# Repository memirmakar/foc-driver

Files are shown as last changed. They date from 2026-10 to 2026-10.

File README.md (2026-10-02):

# FOC Motor Driver — Rev B

Closed-loop FOC driver for 2-phase steppers, BLDC/PMSM and brushed DC motors.
4 half-bridges (2× DRV8300 + CSD19534Q5A), 36–48 V, 5 A continuous, STM32G431RBT6, CAN-FD.

Driver split: U3 drives HB1+HB2+HB3, U4 drives HB4. A BLDC-only board can be built with a single
DRV8300 (U4, Q7, Q8 and the HB4 parts are DNP; they carry a `Variant` field in the schematic).

| Path | Contents |
|---|---|
| `HANDOVER.md` | Rev B handover: decisions, layout guidance, firmware impacts |
| `FOC-surucu-analiz.md` | Technical audit and price survey |
| `BOM_revB.csv` | Rev B bill of materials |
| `hardware/` | KiCad 10 project (4 sheets: MCU, Interfaces, Power Supply, Power Stage) |
| `hardware/build/` | Schematic PDF, sheet PNGs, ERC report |
| `tools/` | Python generator for the schematics (`build.py`), netlist checks (`check_net.py`), renderer |
| `datasheets/` | Reference datasheets |

The schematics are generated: run `python3 tools/build.py`, then verify with
`kicad-cli sch export netlist` + `python3 tools/check_net.py <netlist>`.
Edits made directly in KiCad are overwritten by the next build.

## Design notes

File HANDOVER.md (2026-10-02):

# FOC Motor Sürücü — Devir (Handover) Dokümanı · Rev B

**Repo:** https://github.com/altinay10/foc-motor-driver (commit `4a430fc`)
**Tarih:** 2026-10-02
**Bu dokümanın amacı:** PCB tasarımını ve komponent değişikliği işini devralacak kişinin, önceki
analiz ve kararları baştan çıkarmak zorunda kalmadan işe başlayabilmesi.

Ekler (bu klasörde):
- `BOM_revB.csv` — revize malzeme listesi (fiyat kaynağı, durum, alternatif sütunlarıyla)
- `FOC-surucu-analiz.md` — ayrıntılı teknik denetim ve fiyat taraması

---

## 1. Proje özeti

Kapalı çevrim FOC motor sürücü kartı.

| Özellik | Hedef |
|---|---|
| Motor tipleri | 2 faz bipolar step (ana hedef), 3 faz BLDC/PMSM, fırçalı DC |
| Güç katı | 4 yarım köprü (HB1–HB4) = 2 H-köprü |
| Bara | 36–48 V |
| Akım | 5 A sürekli/faz, 15 A tepe dayanım |
| Akım ölçümü | In-line shunt + INA240A2, HB1 ve HB3 çıkışında |
| Açı | Kart üstü AS5047D (14 bit, SPI), harici SPI encoder, **yeni:** ABI/Hall girişi |
| Haberleşme | CAN-FD (FDCAN + TJA1051T/3), papatya dizimi |
| PWM | 30 kHz merkez hizalı (20–50 kHz parametre) |
| PCB | 4 katman, hedef 45×45 mm (sığmazsa 50×50) |

Motor eşleşmesi:

| Mod | Bağlantı | Akım ölçümü |
|---|---|---|
| Step | A sargısı HB1–HB2, B sargısı HB3–HB4 | A: RS1, B: RS2 |
| BLDC | U=HB1, V=HB2, W=HB3 (HB4 boşta) — **üç faz da U3'te, tek DRV8300 ile çalışır** | U ve W (V = −U−W) |
| DC | 1–2 adet çift yönlü: HB1+HB2, HB3+HB4 | Her motor için bir shunt |

---

## 2. Repo'nun mevcut durumu (devralırken bilinmesi gerekenler)

| Öğe | Durum |
|---|---|
| `docs/DESIGN.md`, `docs/site/foc-anatomi.html` | Kapsamlı ve büyük ölçüde doğru. **Rev A'yı anlatıyor**, bu dokümandaki Rev B değişiklikleri işlenmedi |
| `hardware/*.kicad_sch` | **~%10–15 tamam.** Sadece MCU, 1× MIC4605, 2× FET, AS5047D, kristal, birkaç C var |
| `hardware/*.kicad_pcb` | **Boş** |
| `hardware/BOM.csv` | Rev A. Yerine `BOM_revB.csv` kullanılacak |
| `firmware/` | Yok (başlanmadı) |
| `simulation/current_loop.py` | Çalışıyor ama **gerilim sınırı modeli hatalı** (bkz. §7) |

Şematikteki tutarsızlıklar:
- MCU sembolü `STM32G474RBTx`. Rev A dokümanı `G431CBT6` diyordu. **Rev B kararı: STM32G431RBT6** (LQFP-64; pin uyumlu sembol `STM32G431RBTx`).
- Net etiketi olarak `PSMQC094N10NS2` kullanılmış (parça numarasına benziyor). Doğru net adlarıyla değiştirilmeli.
- LM5163 (veya LMR38010) için KiCad sembolü yok, çizilmeli. DRV8300 sembolü KiCad standart kütüphanesinde yoksa o da çizilmeli.

---

## 3. Kararlar

### 3.1 Kesinleşenler
| # | Karar | Gerekçe |
|---|---|---|
| K1 | 4 yarım köprü topolojisi | Step 2 faz; aynı donanımla BLDC ve DC |
| K2 | MCU ailesi STM32G4 kalıyor, F4'e geçilmiyor | F4'te CAN-FD, dahili komparatör→BKIN ve CORDIC yok; üstelik daha pahalı ve stoksuz |
| K3 | **Fren chopper kaldırıldı** (Q9, UCC27517, J5 çıktı) | Proje kararı. Etkisi için bkz. §6 R5 |
| K4 | In-line akım ölçümü ve INA240A2 korunuyor | Kalite. Low-side + dahili OPAMP daha ucuz ama yüksek modülasyonda ölçüm penceresi daralıyor |
| K5 | Bootstrap gate sürüşü (charge pump yok) | Tutma torku PWM ile üretiliyor (duruşta duty ≈ %42/%58), %100 duty gerekmiyor |
| K6 | Kapasitör azaltarak maliyet düşürülmeyecek | EMI ve aşırı gerilim |
| K7 | **Sürücü dağılımı: U3 = HB1+HB2+HB3, U4 = HB4** (2026-10-03) | BLDC kartı tek DRV8300 ile üretilebilsin (U4, Q7, Q8 ve HB4 parçaları DNP). Bedeli: step modunda B sargısının iki bacağı farklı entegrede (§4.2) |

### 3.2 Önerilen, onay bekleyen
| # | Öneri | Not |
|---|---|---|
| O1 | **4× MIC4605 → 2× DRV8300DPWR** | Rev A'daki MIC4605-**1** zaten yanlış varyanttı (çift giriş). DRV8300: sabit 150–280 ns dead-time + çapraz iletim kilidi, dahili bootstrap diyotu, ~2.6 $ ucuz |
| O2 | Alternatif: 2× **DRV8353/DRV8350** | FET başına VDS aşırı akım izleme ve fault pini. Daha pahalı; TR kanallarında stok yok. Fiyat araştırılmadı |
| O3 | **STM32G431RBT6** (LQFP-64) | 8 PWM + ABI/Hall + BKIN2 için pin gerekli. Farnell'de CBT6'dan ucuz |
| O4 | 12 V buck → **LM5163** (100 V) | LMR38010'un 80 V mutlak maksimumu TVS kıstırma gerilimi altında kalıyor. DigiKey stoku 0, tedarik kontrol edilmeli |

### 3.3 Açık (karar verilmeli)
- Ters polarite P-FET parça numarası (≥100 V, gate zener'li)
- Bulk kapasitör parça numarası (100 V, ripple akımı hesabına göre)
- Konnektör ailesi (J1/J2 akımı: zincirdeki **toplam** kart akımını taşıyacak)
- GVDD yük anahtarı parçası (§4.4)
- Termal çözüm: soğutucu / motor flanşına termal pad / fan (§4.6)

---

## 4. PCB tasarımcısı için

### 4.1 Rev B blok yapısı
```
48V ─ J1/J2 ─ Q10 ters polarite (P-FET + zener) ─ D1 TVS ─ C_BULK (100V) ─┬─ HB1..HB4 (Q1-Q8)
                                                                           │     └─ alt FET source'lari ─ RS3 (bara shunt) ─ GND
                                                                           └─ U7 LM5163 ─ 12V ─┬─ U10 yuk anahtari ─ GVDD ─ U3 (HB1-3) / U4 (HB4) DRV8300
                                                                                               └─ U8 LMR51430 ─ 3.3V ─ MCU, INA240, CAN, AS5047D
                                                                                                                  └─ FB1 ─ 3.3VA (ADC ref, INA240 REF1, encoder)
```

### 4.2 Gate driver yerleşimi (DRV8300)
- **U3 = HB1 + HB2 + HB3, U4 = HB4 (K7).** BLDC'de U/V/W üç fazı aynı entegrede (kanallar arası gecikme eşleşmesi ±30 ns); BLDC varyantında U4 ve HB4 takılmaz.
- **Bedeli:** step modunda B sargısı (HB3–HB4) iki entegreye bölünür; entegreler arası gecikme farkı 110 ns'ye kadar çıkabilir. 48 V / 30 kHz'te bu ~0.16 V ortalama gerilim hatası demek, büyük ölçüde sabit ofset; kapalı çevrim akım döngüsü (PI integratörü) telafi eder. Firmware'de dead-time kompanzasyonuna bacak başına ofset kalibrasyonu eklenmeli.
- **U3 ve HB1–HB3 FET'leri** birlikte yerleşmeli; U4 HB4'ün yanında durur.
- **Fren chopper (opsiyonel, DNP):** U4 kanal B alt çıkışı (GLB) → Q9 + J9; kontrol BRK_PWM (PB6, TIM8_CH1). U4 kanal C kullanılmıyor. BLDC varyantında (U4 yok) chopper da yoktur.
- **BLDC varyantı DNP listesi:** U4, Q7, Q8, U4 GVDD kondansatörleri, HB4 gate ağı, HB4 bootstrap ve C_HB kondansatörleri. Şematikte bu parçalarda `Variant` alanı dolu. Firmware, U4 takılı değilken step modunu engellemeli.
- GH/SH ve GL/GND döngüleri kısa olmalı. Bootstrap kondansatörü BSTx–SHx pinlerinin dibine konmalı. GVDD'ye ≥10 µF.
- DRV8300'ün tek GND pini var (alt gate dönüşü de buradan). GND'yi alt FET source bölgesine kısa yoldan bağlayın; RS3 bara shunt'ının hangi tarafına referanslanacağını yerleşimde netleştirin (öneri: driver GND = RS3'ün GND tarafı, alt FET source'ları RS3'ün üst tarafı; gate dönüş yolu shunt üzerinden geçer ama düşüm mV mertebesinde).
- Gate direnci: turn-on 33 Ω, turn-off 10 Ω + diyot. **FET'in kapanma süresi 150 ns'nin (min dead-time) altında kalmalı.** Turn-off direnci büyütülmemeli.
- Girişlerde (INHx/INLx) dahili pull-down var. Yine de MCU reset durumunda köprünün kapalı kaldığını doğrulamak için hatlara harici 10–100 kΩ pull-down konabilir.

### 4.3 Akım ölçümü ve koruma
- RS1/RS2: **Kelvin** bağlantı, INA240 girişlerine kısa, sıkı ve GND korumalı diferansiyel çift.
- INA240 **REF1 → 3.3VA** (dijital 3V3'e değil). REF2 → AGND.
- **RS3 (yeni):** tüm alt FET source'ları → RS3 → GND. G431 dahili OPAMP (PGA) → dahili COMP → TIM1_BKIN. Böylece HB2/HB4 kısa devresi, FET delinmesi ve shoot-through yakalanır (in-line shunt'lar bunları görmez).
- Faz akımı sinyalleri **COMP_INP olabilen pinlere** atanmalı (§5).

### 4.4 Donanımsal ENABLE (önemli, Rev A'dan farklı)
DRV8300'de EN pini **yok**. Bu yüzden ENABLE şöyle uygulanmalı:
1. Harici ENABLE (J6) → **TIM1_BKIN2** pini: CPU'dan bağımsız olarak timer çıkışlarını idle'a (tüm FET'ler kapalı) çeker.
2. Harici ENABLE **AND** MCU_EN (U11, 74LVC1G08) → **U10 GVDD yük anahtarı**: 12 V gate besleme kesilir, DRV8300 UVLO'ya girer, tüm FET'ler kapanır. MCU kilitlense bile çalışır.
3. ENABLE hattına pull-down: konnektör çıkarılırsa sürücü kapalı kalmalı.

### 4.5 Güç katı ve EMI
- Her bacakta **2× 2.2 µF 100 V X7R 1210** (C_HB), üst FET drain ile alt FET source arasında, mümkün olan en küçük döngüde.
- Güç döngüsü: bulk → üst FET → alt FET → RS3 → GND, en küçük alan. 4 bacak birbirinin kopyası olarak yerleşmeli.
- Katman dizilimi (Rev A'dan): Sinyal/Güç — **kesintisiz GND** — GND/Güç — Sinyal. GND düzlemi bölünmeyecek.
- Encoder ve analog bölge anahtarlamadan fiziksel olarak ayrı; besleme FB1 üzerinden.
- **AS5047D alt yüzde, kartın tam merkezinde** (mıknatısla hizalı). Yerleşim buradan başlar.

### 4.6 Termal
- Tahmini kayıp 3.3 W (30 kHz) – 4.7 W (50 kHz). 45×45 mm'de doğal konveksiyonla **+55…80 °C** artış bekleniyor → soğutma şart.
- FET altlarında termal via tarlası, iç katman bakırları geniş tutulmalı.
- NTC (RT1) FET bakırına yakın.
- Montaj delikleri / termal pad alanı soğutucu veya motor flanşı için planlanmalı.

### 4.7 CAN ve konnektörler
- J1/J2: 48 V + GND + CANH + CANL. Akım değeri zincirdeki toplam akıma göre seçilmeli.
- CAN: **split terminasyon** (2× 60.4 Ω + 4.7 nF, jumper ile seçilebilir) + **PESD2CANFD** ESD.
- J5 (fren direnci) kaldırıldı.
- **J8 (yeni):** ABI encoder / Hall, 5 pin: 5V, GND, CH1, CH2, CH3. Her hatta seri direnç + 3.3 V'a klemp, seçilebilir pull-up (open-collector Hall için).
- Q10 P-FET: gate-source 12–15 V zener + seri direnç (48 V, V_GS ±20 V sınırını aşar).
- Sıcak takma (hot-plug) ani akımı için soft-start/inrush sınırlama değerlendirilmeli.

---

## 5. MCU sinyal listesi (STM32G431RBT6) — pin haritası CubeMX'te yapılacak

Rev A'daki LQFP-48 haritası **geçersiz.** Aşağıdaki sinyaller ve kısıtlarla CubeMX'te yeni harita çıkarılmalı.

| Sinyal | Adet | Çevrebirim | Kısıt |
|---|---|---|---|
| PWM INH/INL HB1–HB3 | 6 | TIM1 CH1/CH1N, CH2/CH2N, CH3/CH3N | Complementary + DTG |
| PWM INH/INL HB4 | 2 | TIM1 CH4/CH4N **veya** TIM1'e senkron TIM8 | CH4N pin müsaitliğini doğrula |
| Faz A akımı | 1 | ADC + **COMP_INP** | COMP3_INP = PA0/PC1, COMP1_INP = PA1/PB1, COMP2_INP = PA7/PA3, COMP4_INP = PB0 |
| Faz B akımı | 1 | ADC + **COMP_INP** | Rev A'daki PA4 COMP girişi değildi, **kullanılmamalı** |
| Bara akımı (RS3) | 1 | OPAMP VINP → dahili COMP → TIM1_BKIN | OPAMP giriş pinini doğrula |
| Harici ENABLE | 1 | TIM1_BKIN2 + GPIO | + U11 AND kapısına |
| MCU_EN | 1 | GPIO out | U11'e |
| FDCAN1 RX/TX | 2 | FDCAN1 | PB8 kullanılırsa `nSWBOOT0 = 0` option byte |
| SPI1 (AS5047D) | 4 | SPI1 | |
| SPI2 (harici encoder) | 4 | SPI2 | |
| ABI/Hall (J8) | 3 | TIM3 veya TIM4 CH1–CH3 | Encoder modu + Hall (XOR) arayüzü aynı timer'da |
| VBUS, NTC, CAN adres | 3 | ADC | |
| USART2 debug | 2 | USART2 | |
| GPIO giriş ×2, aux çıkış ×1 | 3 | GPIO | Aux = Q11 |
| LED ×2 | 2 | GPIO | |
| SWD, OSC_IN/OUT, NRST | 5 | | |

---

## 6. Bilinen sorunlar ve riskler

| # | Sorun | Önem | Durum |
|---|---|---|---|
| R1 | MIC4605-1 yanlış varyant (çift giriş); tek PWM planıyla köprü çalışmazdı | Kritik | DRV8300 ile çözülüyor (O1) |
| R2 | Faz B'de donanım aşırı akım koruması yok (PA4 COMP girişi değil), A'da tek yönlü | Kritik | Pin haritası + RS3 ile çözülecek |
| R3 | HB2/HB4 kısa devresi ve shoot-through hiçbir sensörde görünmüyor | Kritik | RS3 bara shunt'ı (yeni) |
| R4 | ENABLE yazılıma bağlıydı | Kritik | §4.4 |
| R5 | **Chopper kaldırıldı** → rejenerasyonda bara gerilimi yükselir, TVS sürekli enerjiyi kaldıramaz | Yüksek | Firmware: VBUS izleme, yavaşlama rampası sınırı, gerekirse sıfır vektör frenleme. Opsiyonel chopper footprint (§4.2) |
| R6 | Gerilim koordinasyonu: 63 V kapasitör, SMBJ58A kıstırma 93.6 V > LMR38010 80 V | Yüksek | 100 V kapasitör, SMCJ54A, LM5163 |
| R7 | Termal: soğutmasız +55…80 °C | Yüksek | §4.6 |
| R8 | DRV8300 sabit 150–280 ns dead-time → bacak başına ~0.3 V bozulma | Orta | Firmware'de dead-time kompanzasyonu (kalibrasyonlu) |
| R9 | DRV8300'de fault pini, VDS izleme, sıcaklık koruması yok | Orta | RS3 + NTC + firmware; ya da O2 (DRV8353) |
| R10 | Simülasyon gerilim sınırı hatalı → hız tavanı ~%30 iyimser (571 → ~405 rpm) | Orta | §7 |
| R11 | CAN terminasyonu ve ESD yoktu | Orta | BOM'a eklendi |
| R12 | Bootstrap %100 duty'de dolamaz | Düşük | Firmware duty sınırı %97–98 |

---

## 7. Firmware'e etki eden donanım kararları

- **Duty sınırı:** SVPWM dahil %97–98 (bootstrap yenilenmesi için ≥0.5–1 µs off süresi).
- **Bootstrap ön şarj:** Her enable'da ve Hi-Z sonrasında alt FET'ler kısa süre açılmalı.
- **Dead-time:** MCU DTG yedek amaçlı (ör. 50–100 ns). Etkin dead-time ~215 ns (driver). Akım yönüne göre gerilim kompanzasyonu gerekir.
- **nSWBOOT0 = 0** option byte (FDCAN RX PB8'e düşerse) — ilk programlamada.
- **Chopper yok:** VBUS eşik izleme, rejeneratif frenlemede akım/rampa sınırı.
- **Simülasyon düzeltmesi:** `current_loop.py` içindeki `max_current_at_speed` dq'da kare değil daire sınırı kullanmalı: `(R·iq + ωe·λm)² + (ωe·L·iq)² ≤ Vbus²`. λm tutma torkundan türetilirken `|i| = √2·I_anma` alınmalı (tutma torku iki faz birden enerjiliyken ölçülür).

---

## 8. Komponent değişikliği iş paketi

Ayrıntı `BOM_revB.csv` içinde. Fiyatlar 2026-10-02 taramasından, 10 adet kademesi.

**Sonuç:** komponent toplamı Rev A **~61.5 $ → Rev B ~48.5 $** (PCB hariç). Bu toplamın ~22 $'ı "TAHMIN" veya "BOM tahmini" kaynaklı; doğrulanması gerekiyor.

Tedarik notları:
- **Özdisan:** Çoğu parça stoksuz, "Fiyat ve Stok Talep Et". Stoklu ve en ucuz olduğu kalem CSD19534Q5A (0.46 $, 474 adet). DRV8300DPWR 0.47 $ (talep üzerine).
- **DigiKey:** MCU, INA240, DRV8300, TJA1051 stoklu. CSD19534Q5A sadece 3 adet, LM5163 stok 0.
- **Farnell TR:** G431RBT6 en ucuz burada (10+: 4.79 €). DRV8300 ve LMR38010 yok. INA240A2 sadece TSSOP (A2PWR).
- AS5047D artık Infineon markasıyla satılıyor: DigiKey `AS5047D-ATST-TSSOP14`. Farnell'deki ams AS5047D-ATSM "üretimden kaldırıldı".

Yapılacaklar:
- [ ] "TAHMIN" ve "ACIK" satırlarının parça numarası ve fiyatını netleştir (Q10, Q11, C_BULK, U10, D1, D12, konnektörler)
- [ ] LMR51430'u doğrula; 150 mA yük için daha küçük/ucuz bir buck değerlendir
- [ ] LM5163 stoğu yoksa LM5164 veya başka bir 100 V buck seç (LMR38010 ancak TVS stratejisi değişirse)
- [ ] O1/O2 kararı: DRV8300 mü DRV8353 mü (DRV8353 fiyat/stok araştırması)
- [ ] Bulk kapasitör ripple akımı hesabı (2 H-köprü, 5 A, 30 kHz)
- [ ] Her parça için KiCad sembol + footprint (proje kütüphanesine, `${KIPRJMOD}` ile)
- [ ] BLDC (tek sürücü) varyantı için ayrı BOM / montaj varyantı (K7)

---

## 9. Bring-up ve doğrulama listesi

1. Saat, SWD, LED, UART; `nSWBOOT0 = 0`; CAN bağlıyken normal boot.
2. GVDD yük anahtarı ve ENABLE zinciri: ENABLE düşünce GVDD'nin kesildiğini ölç.
3. Motorsuz, düşük bara geriliminde (12–24 V) PWM: her bacakta **V_GS(üst) ve V_GS(alt) aynı anda** osiloskopla → dead-time ve turn-off < 150 ns doğrulaması. Sonra 48 V'ta ve sıcakken tekrar.
4. RS3 + COMP → BKIN: kontrollü kısa devre testi (akım sınırlı kaynakla).
5. INA240 ofset kalibrasyonu (PWM açık, motor bağlı değil).
6. AS5047D ham açı → açık çevrim döndürme → encoder↔elektriksel açı kalibrasyon tablosu.
7. Akım döngüsü (tork modu), dead-time kompanzasyonu ayarı.
8. Hız ve pozisyon döngüsü; tutma torku testi (5 A, duruşta, termal gözlem).
9. Rejeneratif frenleme testi: chopper yokken VBUS yükselmesini ölç.
10. İki kartla CAN-FD papatya dizimi.

---

## 10. Kaynaklar
- DRV8300 datasheet (TI SLVSFG5D): https://www.ti.com/lit/ds/symlink/drv8300.pdf
- MIC4605 datasheet (Microchip DS20005853): https://download.mikroe.com/documents/datasheets/mic4605.pdf
- STM32G431 datasheet: https://www.mouser.com/datasheet/2/389/stm32g431c6-1600866.pdf
- Fiyat/stok: digikey.com, tr.farnell.com, ozdisan.com (2026-10-02)

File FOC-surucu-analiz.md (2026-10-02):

# FOC Motor Sürücü (altinay10/foc-motor-driver) — Teknik Denetim ve Maliyet Analizi

Tarih: 2026-10-02 · İncelenen commit: `4a430fc` (Initial import)

---

## 0. Kontrol listesi (neye bakıldı)

| # | Konu | Sonuç |
|---|---|---|
| 1 | Repo durumu (şematik / PCB / firmware olgunluğu) | ⚠️ Erken aşama |
| 2 | Gate driver seçimi ve pin planı tutarlılığı | ❌ **Kritik hata** |
| 3 | Dead-time / shoot-through koruması | ⚠️ Kısmen |
| 4 | Aşırı akım / kısa devre koruması | ❌ Boşluk var |
| 5 | ENABLE / güvenli durma | ❌ Yazılıma bağlı |
| 6 | Gerilim koordinasyonu (TVS, kapasitör, regülatör, driver) | ❌ Tutarsız |
| 7 | Ters polarite / hot-plug / daisy-chain gücü | ⚠️ Eksik detay |
| 8 | Akım ölçüm zinciri (INA240, referans, ADC) | ✅ İyi, küçük düzeltme |
| 9 | MCU seçimi, pin bütçesi, çevrebirim eşleşmesi | ⚠️ Pin yetmiyor |
| 10 | Simülasyon / hız-tork zarfı hesabı | ❌ Hesap hatası |
| 11 | Termal bütçe | ⚠️ Soğutmasız tutmaz |
| 12 | CAN-FD arayüzü | ⚠️ Terminasyon/ESD yok |
| 13 | 4 yarım köprü / step motor desteği | ✅ |
| 14 | BLDC desteği | ✅ FOC için, sınırlamalarla |
| 15 | DC motor desteği (donanım değişmeden) | ✅ Sınırlamalarla |
| 16 | G4 → F4 değişimi | ❌ Önerilmez |
| 17 | 4× MIC4605 → 2× DRV8300 | ✅ Uygulanabilir, önerilir |
| 18 | Fiyat/stok (DigiKey, Farnell, Özdisan) | Aşağıda |

---

## 1. Genel değerlendirme

**Tasarım düşüncesi güçlü, donanım uygulaması henüz yok denecek kadar az.**

- `docs/DESIGN.md` ve `foc-anatomi.html` iyi yazılmış; topoloji (4 yarım köprü), in-line shunt + INA240,
  50 kutup çifti etkisi, encoder kalibrasyon zorunluluğu, anti-windup, dq ileri besleme gibi kararlar doğru.
- **Ama:**
  - Şematikte sadece ~30 sembol var: 1× MIC4605, 2× FET, MCU, AS5047D, kristal, birkaç kapasitör.
    Güç katı, akım ölçümü, CAN, regülatörler, konnektörler **çizilmemiş**.
  - Şematikteki MCU sembolü **STM32G474RBTx (LQFP-64)**, dokümandaki ise **STM32G431CBT6 (LQFP-48)** — tutarsız.
  - Net etiketi olarak `PSMQC094N10NS2` kullanılmış (parça numarasına benziyor, net adı değil).
  - PCB dosyası boş (80 bayt), firmware klasörü yok.
  - BOM'daki fiyatlar EKOM'dan ve birçok satır "ACIK" (parça seçilmemiş).

Sonuç olarak "ne kadar iyi" sorusunun cevabı: **konsept seviyesinde 7/10, uygulanabilir donanım seviyesinde
henüz değerlendirilemez.** Aşağıdaki kritik hatalar düzeltilmeden kart basılırsa çalışmaz ya da güvenli olmaz.

---

## 2. Kritik bulgular (kart basılmadan önce düzeltilmeli)

### 2.1 ❌ MIC4605-1 yanlış varyant — tasarım bu haliyle çalışmaz
BOM: `MIC4605-1YM … tek PWM girişi`. Datasheet (DS20005853):
- **MIC4605-1 = çift giriş (HI + LI)**
- **MIC4605-2 = tek PWM girişi**

Tasarımın pin planı tek PWM + ortak EN (4 PWM + 1 EN). -1 ile LI pini 300 kΩ dahili pull-down ile
sürekli düşük kalır → alt FET hiç açılmaz → bootstrap kondansatörü dolmaz → üst FET de sürülemez.
**Çözüm:** ya MIC4605-**2** (aynı fiyat, aynı kılıf), ya da aşağıdaki DRV8300 + LQFP-64 seçeneği.

### 2.2 ❌ Aşırı akım koruması pin eşleşmesi tutmuyor
Doküman: "COMP → TIM1_BKIN, harici parça yok". STM32G431'de komparatör pozitif girişleri:
COMP1_INP = PA1/PB1, COMP2_INP = PA7/PA3, COMP3_INP = PA0/PC1, COMP4_INP = PB0/PE7.
- Faz A akımı **PA0** → COMP3 ✓ (ama yalnız **tek yön**; stepte akım çift yönlü)
- Faz B akımı **PA4** → **hiçbir komparatörün INP'si değil** ✗ → B fazında donanım OCP yok.
- Her pin yalnız bir komparatöre gidiyor → çift yönlü (±) eşik için ya sinyali iki pine bağlamak ya da
  ayrı bir bara akımı ölçümü gerekir. (Pin eşleşmesini CubeMX'te teyit edin.)

### 2.3 ❌ HB2 / HB4 ve shoot-through için hiç koruma yok
Shunt'lar yalnız HB1 ve HB3 çıkışında. Şu arızaları **hiçbir sensör görmez**:
- A− veya B− terminalinin GND'ye / VBUS'a kısa devresi (akım HB2/HB4 FET'inden geçer, shunt'tan geçmez)
- Köprü içi shoot-through ya da delinmiş FET (in-line shunt köprü içi akımı görmez)

**Çözüm (ucuz):** DC bara dönüşüne tek bir low-side shunt (2–5 mΩ) + G431'in dahili OPAMP'ı (PGA) +
dahili COMP → TIM1_BKIN. ~0.5 $ ek maliyet, tüm köprü arızalarını ve bara akımını kapsar.
Bonus: bara akımı ölçümü güç/rejenerasyon kestirimi ve fren chopper kontrolü için de işe yarar.

### 2.4 ❌ "Donanımsal ENABLE" aslında yazılımsal
Harici ENABLE girişi PB7'ye (GPIO in) gidiyor; driver EN'i PB6'dan MCU sürüyor. MCU kilitlenirse veya
firmware hatası varsa ENABLE düşse bile köprü kapanmaz. DESIGN.md §11'deki "Sertifikalı STO yerine
donanımsal ENABLE yeterli" iddiası bu şemayla geçersiz.
**Çözüm:** ENABLE'ı (a) bir 74LVC1G08 AND kapısıyla driver EN hattına donanımsal olarak bağlayın,
(b) ayrıca TIM1_BKIN2 pinine verin. EN ve PWM hatlarına pull-down koyun (reset/boot sırasında MCU pinleri
yüzerken köprü kapalı kalsın).

### 2.5 ❌ Gerilim koordinasyonu tutarsız
| Eleman | Değer |
|---|---|
| Bara | 36–48 V (13S Li-ion dolu: **54.6 V**) |
| Fren chopper devreye girme | ~54 V ← 13S dolu batarya ile çakışır |
| SMBJ58A | V_BR min **64.4 V**, kıstırma V_C **93.6 V** (@I_pp) |
| Bulk kapasitör | **63 V** ← TVS iletime geçmeden aşılır |
| LMR38010 | abs max **80 V** ← TVS kıstırması bunu aşar |
| MIC4605 HS | abs max 90 V |

**Çözüm:** Kapasitörleri 80–100 V'a çıkarın; 12 V buck'ı 100 V'luk LM5163/LM5164'e geçirin (fiyat aynı);
TVS'i SMCJ54A gibi daha yüksek I_pp'li bir parçayla değiştirin ki kıstırma gerilimi düşük kalsın;
asıl aşırı gerilim koruması fren chopper'dır, eşiğini parametre yapın.

### 2.6 ❌ Simülasyondaki gerilim sınırı hatalı → hız tavanı ~%30 iyimser
`simulation/current_loop.py` gerilim sınırını **dq çerçevesinde kare** alıyor (|v_d| ≤ Vbus ve |v_q| ≤ Vbus
ayrı ayrı). Bağımsız H-köprülerin kare sınırı **sabit αβ çerçevesindedir**; dq çerçevesi döndükçe bu kare
de döner, her açıda garanti olan sınır içteki dairedir: √(v_d² + v_q²) ≤ Vbus.

Yeniden hesap (NEMA23, R=1.5 Ω, L=3 mH, 48 V, 5 A):

| λm varsayımı | Model | Tam akımın korunduğu son hız |
|---|---|---|
| 13.6 mWb (repo) | kare (repo) | 9.5 dev/s (571 rpm) |
| 13.6 mWb (repo) | **daire (doğru)** | **6.75 dev/s (405 rpm)** |
| 9.6 mWb | daire | 7.8 dev/s (471 rpm) |

Ek not: λm tutma torkundan `T/(p·I)` ile türetilmiş. Tutma torku iki faz birden anma akımındayken
ölçülür, bu yüzden |i| = √2·I_anma alınmalı; böyle hesaplanınca λm ≈ 9.6 mWb olur. Tablodaki 3.39 N·m
gibi değerler de 2.8 A'lik bir motoru 5 A'de lineer kabul ediyor; doyum nedeniyle gerçekte daha düşük çıkar.

---

## 3. Dead-time koruması — tam mı?

**Kısa cevap: Tam değil.** Tek katmanlı ve doğrulanmamış.

| Katman | Mevcut tasarım (MIC4605-2 varsayımıyla) |
|---|---|
| MCU dead-time (TIM1 DTG) | **Yok.** Tek PWM girişli driver'da complementary çıkış kullanılmıyor |
| Driver dead-time | Adaptif: HS→LS geçişinde switch node (HS < 2.2 V) izleniyor ✓; LS→HS geçişinde ise **LO pin** gerilimi (< 1.9 V) izleniyor |
| Driver interlock | Var (tek PWM girişiyle iki çıkışın birden açık olması mantıksal olarak imkânsız) ✓ |
| Arıza geri bildirimi | Yok (MIC4605'te fault pini yok) |
| Shoot-through algılama | Yok (bkz. 2.3) |

**Zayıf nokta:** LO pini 1.9 V'un altına indiğinde FET kapısı hâlâ yüksek olabilir, çünkü arada
10 Ω + diyot + FET'in iç R_g'si var. Datasheet de harici sönümleme direncinin kapanma gecikmesini
artırdığını açıkça yazıyor. Datasheet'teki dead-time < 20 ns. Pratikte bu yönde marjı sağlayan şey,
üst FET'in 33 Ω üzerinden yavaş açılması — bu da tesadüfi bir marj, tasarlanmış değil.

**Ek riskler:**
- %100 duty'de bootstrap şarj olamaz. `duty = 0.5 + v/(2·Vbus)` doyumda 1'e gider → firmware'de
  %95–97 ile sınırlanmalı.
- Adaptif dead-time akım yönüne ve sıcaklığa göre değiştiği için, düşük hızda gerekli olan
  dead-time kompanzasyonu daha zor (sabit bir dead-time ile deterministik olurdu).

**Önerilen çözüm (çift katman):**
complementary PWM + MCU DTG (ör. 100–150 ns) **+** driver'ın kendi interlock'u.
Bunun için DRV8300D (6x giriş, sabit 200 ns + cross-conduction engeli) veya MIC4605-1 (HI/LI, adaptif +
"ilk açılan kazanır" kilidi) kullanılabilir — ikisi de yarım köprü başına 2 pin ister → LQFP-64 MCU.
Bring-up'ta her köprüde V_GS(alt) ile V_GS(üst) aynı anda osiloskopla ölçülmeli.

---

## 4. 4× MIC4605 yerine 2× DRV8300 olur mu?

Önce bir düzeltme: Mevcut tasarımda her MOSFET için ayrı driver yok, **her yarım köprü için bir driver**
var (8 FET'e 4 driver). DRV8300 tek pakette **3 yarım köprü** sürer → 2 adet = 6 kanal.

**Evet, olur ve önerilir.** Kanal dağılımı:

| Kanal | Kullanım |
|---|---|
| 1–4 | HB1–HB4 |
| 5 (yalnız low-side) | Fren chopper FET'i → **UCC27517 kalkar** |
| 6 | Yedek (ör. ikinci low-side çıkış) |

| | 4× MIC4605-2 | 2× DRV8300DPW |
|---|---|---|
| Gerilim | HS 90 V abs | SHx 85 V çalışma, BST 125 V abs, SHx −22 V tolerans |
| Dead-time | Adaptif (~20 ns) | Sabit 200 ns (TSSOP) + cross-conduction engeli |
| Giriş | 1 PWM / köprü | 2 giriş / köprü (6x) → **MCU dead-time + bacak başına Hi-Z** |
| Bootstrap diyot | Dahili | Dahili (D versiyonu) |
| Gate akımı | 1 A | 0.75 A kaynak / 1.5 A çekme (zaten R_g ile yavaşlatılıyor) |
| Fiyat (10 adet) | 4 × 1.05 $ = **4.20 $** (DK) | 2 × 0.81 $ = **1.62 $** (DK); Özdisan 0.47 $/adet |
| UCC27517 | Gerekli (~0.6–1.2 $) | Gereksiz |

**Bedeli:** 8 PWM hattı gerekiyor. LQFP-48'de pin kalmadığı için **STM32G431RBT6 (LQFP-64)** gerekir —
Farnell'de CBT6'dan daha ucuz (aşağıda). Dördüncü köprü için TIM1_CH4/CH4N veya TIM1 ile senkronize
TIM8 kullanılabilir (CubeMX'te teyit edin).

Varyant notu: `DRV8300DPWR` = INL non-inverting (6x complementary PWM için doğru seçim, en çok stoklu).
`DRV8300DIPWR` = INL inverting (INH=INL bağlanırsa tek-PWM modu, ama DigiKey'de daha pahalı).

---

## 5. 4 faz / step + BLDC + DC motor desteği

### 5.1 Step motor (2 faz bipolar, 4 yarım köprü) — ✅ Tam destek
TIM1 CH1–CH4 bağımsız, iki H-köprü, iki in-line shunt. 6/8 telli unipolar motorlar bipolar olarak bağlanabilir.

### 5.2 BLDC (3 faz) — ✅ FOC için evet, kısıtlarla
- HB1/HB2/HB3 = U/V/W; shunt'lar U ve W'de, V = −(U+W). FOC + SVPWM için yeterli.
- **Kısıtlar:**
  - Ortak EN olduğu için bacak başına Hi-Z yok → 6-step trapez ve BEMF sıfır geçişli sensörsüz çalışma yapılamaz (sensörlü ya da gözlemcili FOC yapılabilir).
  - **Hall girişi yok** (J6'da yalnız 2 giriş var, 3 gerekir, 5 V seviye koruması da yok).
  - Açı ölçümü yalnız kart üstü AS5047D (mıknatıs kartın merkezine hizalı olmalı) veya SPI harici encoder ile.
  - Faz gerilimi ölçümü yok (sensörsüz başlatma / flying start zorlaşır).
- DRV8300 + LQFP-64 önerisi bu kısıtların ilk ikisini kaldırır.

### 5.3 DC motor (donanım değiştirmeden) — ✅ Evet, kısıtlarla
- 1 adet çift yönlü fırçalı DC: HB1+HB2, akım RS1 ile ölçülür ✓ (tork/akım kontrolü, rejeneratif fren).
- 2 adet çift yönlü DC: HB1+HB2 ve HB3+HB4, her birinde bir shunt ✓.
- 4 adet tek yönlü DC (her yarım köprüden GND'ye) yapılabilir, ama yalnız ikisinin akımı ölçülür.
- **Kısıtlar:**
  - **Quadrature (ABI) encoder girişi yok** — çoğu DC redüktörlü motorda ABI encoder var → pozisyon kontrolü için donanım değişikliği gerekir (LQFP-64 ile TIM3/TIM4 encoder modu).
  - Ortak EN yüzünden köprü başına "coast" (serbest bırakma) yok; yalnız fren (iki bacak aynı duty) mümkün.
  - 4 mΩ shunt ile ölçüm aralığı ±8.25 A; yüksek akımlı DC motor için 2 mΩ seçeneği var.

---

## 6. G431 yerine F4? — ❌ Önerilmez

| MCU | CAN | CORDIC/FMAC | Dahili COMP→BKIN | DigiKey 10 ad. | DigiKey 100 ad. | Stok (DK) |
|---|---|---|---|---|---|---|
| **STM32G431CBT6** (mevcut) | **FDCAN (CAN-FD)** | ✓ | ✓ (4×) | 5.39 $ | 4.53 $ | 280 |
| **STM32G431RBT6** (öneri, LQFP-64) | FDCAN | ✓ | ✓ | 5.43 $ | 4.57 $ | 6575 |
| STM32G431C8T6 (64 KB) | FDCAN | ✓ | ✓ | 4.40 $ | 3.68 $ | 18 |
| STM32F446RET6 | bxCAN (FD yok) | ✗ | ✗ | 7.98 $ | 6.78 $ | 0 |
| STM32F405RGT6 | bxCAN (FD yok) | ✗ | ✗ | 9.78 $ | 8.35 $ | 0 |

F4'ler **daha pahalı**, stokta yok ve README'deki CAN-FD papatya dizimi şartını karşılamıyor.
F401/F411 gibi ucuz F4'lerde hiç CAN yok. G4 bu iş için hem en ucuz hem en doğru aile.
**Öneri:** G431**RB**T6 — Farnell'de CBT6'dan ucuz (10+: 4.79 € vs 5.66 €), stok bol ve pin sorununu çözüyor.
(Şematikte zaten LQFP-64 G474 sembolü var; G474 gereksiz pahalı, G431RB yeterli.)

---

## 7. Diğer bulgular (orta / düşük öncelik)

1. **Termal:** 3.3–4.7 W kayıp, 45×45 mm kartta doğal konveksiyonla ~16–25 K/W → **+55…80 °C** artış.
   Motor flanşına termal pad ile ısı yolu, küçük bir soğutucu ya da hava akışı şart. Alternatif olarak dV/dt
   0.5 yerine ~1.2 V/ns hedeflenirse anahtarlama kaybı düşer.
2. **INA240 REF1 → +3.3 V (dijital)**, ADC referansı ise +3.3VA (FB1 ile filtreli). REF1'i 3.3VA'ya
   bağlayın; ratiometrik olsun, dijital gürültü ofset olarak ölçüme binmesin.
3. **Low-side yerine in-line seçiminin gerekçesi yanlış ifade edilmiş:** Tasarımın kendi modülasyonunda
   (duty = 0.5 + v/2Vbus) duruşta duty ≈ %50, yani low-side penceresi en geniş. Low-side ölçümün kör
   kaldığı yer **yüksek modülasyon**, düşük duty değil. In-line yine de daha iyi bir seçim (pencere kısıtı yok),
   INA240'ı koruyun — sadece dokümandaki gerekçe düzeltilmeli.
4. **Yarım köprü başına lokal 100 V MLCC** (ör. 2× 2.2 µF 1210 X7R) BOM'da açıkça yok ("PASIF" içinde
   kaybolmuş). EMI ve aşırı gerilim sıçraması için zorunlu — **maliyet düşürme sırasında kesinlikle çıkarılmamalı.**
5. **Ters polarite P-FET:** 48 V'ta V_GS ±20 V'u aşar → gate–source zener (12–15 V) + seri direnç gerekli.
   Daisy-chain'de hot-plug ani akımı (bulk kapasitör şarjı) konnektörde ark yapar → soft-start veya
   inrush sınırlayıcı (ör. LM74700 + FET ya da NTC) düşünün. Papatya dizimindeki ilk konnektörden
   N kartın toplam akımı geçer; konnektör akım sınıfını buna göre seçin.
6. **CAN:** Terminasyon (split 2×60 Ω + jumper/switch) ve CAN ESD diyotu (ör. PESD2CANFD) yok.
   TJA1051'in ±58 V bus hata toleransı 48 V ile aynı konnektör için iyi bir seçim ✓.
7. **SW1 (BOOT/RESET SPDT) + 10 kΩ → BOOT_PIN:** nSWBOOT0=0 yaklaşımında BOOT0 pinine gerek yok ve PB8
   CAN RX ile paylaşımlı. Kaldırın ya da NRST butonuna çevirin.
8. **Ripple formülü (§4.4):** İki bacak aynı taşıyıcıyla merkez hizalı sürüldüğünde sargı 3 seviyeli ve 2f'de
   görür → ΔI ≈ Vbus/(8·L·f). Gerçek ripple dokümandakinin yarısı (lehte bir hata).
9. **Pin bütçesi:** 33/35 dolu; harici ABI encoder, Hall, bacak başına EN, bara akımı ve BKIN2 için yer yok → LQFP-64.
10. **AS5047D artık Infineon markasıyla satılıyor** (DigiKey: `AS5047D-ATST-TSSOP14`); Farnell'de ams
    AS5047D-ATSM "üretimden kaldırıldı" görünüyor. Parça numarasını güncelleyin.

---

## 8. Fiyat / stok taraması (2026-10-02)

Fiyatlar: DigiKey USD, Farnell TR EUR (KDV hariç), Özdisan USD (KDV hariç). Değerler sitelerde görülen
kademeli fiyatlardır; anlık değişebilir.

| Parça | BOM (EKOM) | DigiKey | Farnell TR | Özdisan |
|---|---|---|---|---|
| STM32G431CBT6 | 5.24 $ | 1: 7.04 · 10: 5.39 · 100: 4.53 $ (stok 280) | 1: 7.39 · 10: 5.66 · 100: 4.61 € (stok 2424) | stok 0, talep üzerine |
| **STM32G431RBT6** | — | 1: 7.08 · 10: 5.43 · 100: 4.57 $ (stok 6575) | 1: 6.25 · **10: 4.79** · 100: 4.03 € | stok 0, talep üzerine |
| STM32G431C8T6 | — | 1: 5.78 · 10: 4.40 · 100: 3.68 $ (stok 18) | — | listelenmiyor |
| MIC4605-1YM-TR | 1.26 $ | 1–10: 1.05 · 100: 0.86 $ (stok 2460) | 1: 0.91 · 100: 0.74 € (stok 2054) | stok 0 (-1YM-T5) |
| MIC4605-2YM(-TR) | — | 1–10: 1.05 · 100: 0.86 $ (stok 2170) | 1: 0.90 · 100: 0.73 € (stok 475) | — |
| **DRV8300DPWR** | — | 1: 1.12 · 10: 0.81 · 100: 0.65 $ (stok 6160) | yok | **1: 0.47 · 100: 0.44 $** (stok 0, talep) |
| DRV8300DIPWR | — | 1: 1.65 · 10: 1.21 · 100: 0.97 $ (stok 991) | yok | — |
| INA240A2D / A2DR | 4.54 $ | A2D: 10: 2.85 · 100: 2.40 $ (stok 7317); A2DR stok 0 | A2PWR (TSSOP): 10: 2.24 · 100: 1.85 € (stok 1292) | A2DR stok 0, talep |
| INA241A2IDR | — | 10: 2.59 · 100: 2.14 $ (stok 0) | — | — |
| AD8418AWBRZ | — | 10: 3.30 $ (stok 78) | — | — |
| AS5047D | 8.92 $ | Infineon AS5047D-ATST: 1: **6.80 $** (stok 4500) | AS5047D-ATSM: üretimden kaldırıldı | AS5047D-ATSM stok 0 |
| MA732GQ-Z (alternatif) | — | 1: 4.81 · 10: 4.13 · 100: 3.61 $ (stok 1678) | — | — |
| LMR38010SDDAR | 3.94 $ | 1: 2.97 · 10: 2.22 · 100: 1.83 $ (stok 615) | yok | yok |
| LM5163DDAR (100 V) | — | 10: 2.25 · 100: 1.85 $ (stok 0) | — | stok 0, talep |
| UCC27517DBVR | 1.24 $ | UMW muadili: 0.40 $ @10 | — | yok |
| TJA1051T/3 | 1.98 $ | /3/2Z: 10: 1.23 · 100: 0.99 $ (stok 6793) | /3/1J: 10: 1.14 · 100: 0.93 € (stok 6380) | yok |
| CSD19534Q5A | 0.55 $ | 10: 0.995 · 100: 0.66 $ (stok **3**) | Q5AT: 10: 1.19 · 100: 1.02 € (stok 265) | **1: 0.46 · 100: 0.43 $ (stok 474)** |

**Tedarikçi gözlemi:** Özdisan bu parçaların çoğunda stoksuz ("Fiyat ve Stok Talep Et"); stoklu ve en ucuz
olduğu kalem CSD19534Q5A. MCU ve analog için DigiKey/Farnell, FET için Özdisan en mantıklı kombinasyon.

---

## 9. Maliyet düşürme önerileri (kaliteyi düşürmeden)

| Değişiklik | Eski | Yeni (≈10 adet) | Fark/kart | Kalite etkisi |
|---|---|---|---|---|
| 4× MIC4605 + UCC27517 → 2× DRV8300DPWR | 5.04 + 1.24 = 6.28 $ | 1.62 $ (DK) / 0.94 $ (Özdisan) | **−4.7…−5.3 $** | + (MCU dead-time + interlock, bacak başına Hi-Z) |
| INA240A2: EKOM → DigiKey/Farnell | 9.08 $ | 5.70 $ / ~4.9 $ | **−3.4…−4.2 $** | Aynı parça |
| AS5047D: EKOM → DigiKey (Infineon) | 8.92 $ | 6.80 $ | **−2.1 $** | Aynı parça |
| LMR38010: EKOM → DigiKey (ya da LM5163 100 V) | 3.94 $ | 2.22–2.25 $ | **−1.7 $** | LM5163 ile **+** (100 V marj) |
| TJA1051T/3: EKOM → DK/Farnell | 1.98 $ | 1.23 $ / 1.14 € | **−0.75 $** | Aynı |
| CSD19534Q5A ×9: Özdisan | 4.95 $ | 4.17 $ | −0.8 $ | Aynı |
| MCU: G431CBT6 → G431RBT6 | 5.24 $ | 5.43 $ (DK) / 4.79 € (FA) | ≈0 | + (pin sorunu çözülür) |
| **Toplam tasarruf** | | | **≈ −13…−15 $/kart** | |
| Eklenmesi gerekenler (bara shunt, AND kapısı, CAN ESD + terminasyon, pull-down'lar, zener, 100 V kapasitörler) | | | **+1.5…2.5 $** | Güvenlik için zorunlu |
| **Net** | ~61.5 $ | **~49–51 $** | **≈ −11…−12 $ (≈ %18–20)** | Kalite artar |

**Önerilmeyen (kaliteyi düşürür):**
- INA240 → low-side shunt + G4 dahili OPAMP (~4–5 $ tasarruf, ama yüksek modülasyonda ölçüm penceresi daralır).
- AS5047D → MA732 (~2.7 $ ek tasarruf; ama 50 kutup çiftinde açı hatası 50 kat büyüdüğü için doğruluk kritik. Kullanılacaksa mutlaka kalibrasyonla).
- Bulk/lokal kapasitör azaltma — EMI ve aşırı gerilim sıçraması artar.
- UMW "UCC27517" muadili — kaynağı belirsiz; DRV8300'e geçilince zaten gereksiz.

---

## 10. Öncelikli yapılacaklar listesi

1. [ ] Driver kararını verin: **(A)** MIC4605-2 + mevcut pin planı (minimum değişiklik) veya **(B, önerilen)** 2× DRV8300DPWR + G431RBT6 + complementary PWM + MCU dead-time.
2. [ ] Bara akımı için low-side shunt + OPAMP + COMP → BKIN; faz akımlarını COMP_INP pinlerine yeniden atayın.
3. [ ] ENABLE'ı donanımsal yapın: AND kapısı + BKIN2; EN ve PWM hatlarına pull-down.
4. [ ] Gerilim koordinasyonu: 100 V kapasitörler, 100 V buck (LM5163/4), TVS seçimini ve chopper eşiğini revize edin.
5. [ ] `current_loop.py`'deki gerilim sınırını daireye çevirin; λm'yi √2 düzeltmesiyle yeniden türetin.
6. [ ] Termal yolu tanımlayın (soğutucu / motor flanşı / fan).
7. [ ] CAN terminasyonu + ESD; ters polarite FET'ine zener; inrush sınırlama.
8. [ ] Şematiği tamamlayın (doküman ile şematikteki MCU tutarsızlığını giderin, net adlarını düzeltin).
9. [ ] ABI encoder + Hall girişi (LQFP-64 ile) — DC ve BLDC desteği için.
10. [ ] Bring-up'ta dead-time ölçümü: her köprüde V_GS(üst) ve V_GS(alt) aynı anda, tam akım ve sıcakken.

---

### Kaynaklar
- MIC4605 datasheet (Microchip DS20005853) — https://download.mikroe.com/documents/datasheets/mic4605.pdf
- DRV8300 datasheet (TI SLVSFG5D) — https://www.ti.com/lit/ds/symlink/drv8300.pdf · https://www.ti.com/product/DRV8300
- STM32G431 COMP pin eşleşmesi — https://www.mouser.com/datasheet/2/389/stm32g431c6-1600866.pdf · https://community.st.com/t5/stm32-mcus-products/stm32g431-comparator-bug/td-p/675832
- Fiyat/stok: digikey.com, tr.farnell.com, ozdisan.com (2026-10-02 tarihli tarama)

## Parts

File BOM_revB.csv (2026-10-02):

Ref | Parca | MPN | Adet | Birim USD (10 adet) | Toplam USD | Fiyat kaynagi | Durum | Alternatif | Not
U1 | MCU | STM32G431RBT6 | 1 | 5.430 | 5.43 | DigiKey (stok 6575); Farnell 4.79 EUR | DEGISTI (CBT6->RBT6) | STM32G431CBT6 (pin yetmez) | LQFP-64. 8 PWM + ABI/Hall + BKIN2 icin. Pin haritasi CubeMX'te yeniden yapilacak
U2 | Manyetik encoder | AS5047D-ATST-TSSOP14 (Infineon) | 1 | 6.800 | 6.80 | DigiKey 1 adet fiyati (stok 4500) | MPN GUNCELLENDI | AS5047P / MA732GQ-Z (dogruluk dusuk) | Artik Infineon markasiyla. Kart ALT yuzu, tam merkez
U3 | 3 faz gate driver #1 | DRV8300DPWR | 1 | 0.810 | 0.81 | DigiKey (stok 6160); Ozdisan 0.47 USD talep | YENI (4x MIC4605 yerine) | DRV8353/DRV8350 (VDS korumali, degerlendirmede) | HB1+HB2+HB3 (BLDC U/V/W tek entegrede). Non-inverting INL. TSSOP-20
U4 | 3 faz gate driver #2 | DRV8300DPWR | 1 | 0.810 | 0.81 | DigiKey | YENI | DRV8353/DRV8350 | HB4 + kanal B: opsiyonel chopper. BLDC varyantinda DNP (Q7, Q8 ve HB4 parcalari ile birlikte)
U5 | Akim sense A | INA240A2D | 1 | 2.850 | 2.85 | DigiKey (stok 7317) | AYNI PARCA, TEDARIKCI DEGISTI | INA240A2PWR TSSOP (Farnell 2.24 EUR) | HB1 cikisi in-line. REF1 -> 3.3VA (dijital 3V3 degil)
U6 | Akim sense B | INA240A2D | 1 | 2.850 | 2.85 | DigiKey | AYNI | INA240A2PWR | HB3 cikisi in-line
U7 | 48V->12V buck (100V) | LM5163DDAR | 1 | 2.250 | 2.25 | DigiKey (stok 0!) | DEGISTI (LMR38010 80V abs max yetersiz) | LMR38010SDDAR (DK 2.22, stok 615) - sadece TVS revize edilirse | Sembol cizilecek. GVDD + 3.3V buck besler
U8 | 12V->3.3V buck | LMR51430 | 1 | 2.210 | 2.21 | BOM (EKOM) - DOGRULANMADI | AYNI |  | ~150 mA yuk; daha kucuk buck ile ucuzlatilabilir
U9 | CAN-FD transceiver | TJA1051T/3/2Z | 1 | 1.230 | 1.23 | DigiKey (stok 6793); Farnell /3/1J 1.14 EUR | AYNI | TJA1051T/3/1J | Bus pinleri +-58V toleransli
U10 | GVDD yuk anahtari (donanimsal ENABLE) | ACIK - 20V+ yuk anahtari veya P-FET | 1 | 0.400 | 0.40 | TAHMIN | YENI |  | ENABLE AND MCU_EN -> 12V GVDD keser -> UVLO ile tum FET'ler kapanir
U11 | AND kapisi | 74LVC1G08 | 1 | 0.100 | 0.10 | TAHMIN | YENI |  | Harici ENABLE ve MCU_EN birlesimi -> U10
Q1-Q8 | Guc MOSFET | CSD19534Q5A | 8 | 0.464 | 3.71 | Ozdisan (stok 474); DigiKey 0.995 (stok 3) | AYNI (adet 9->8) |  | 100V 8.3mOhm SON5x6. Termal via tarlasi
Q10 | Ters polarite P-FET | ACIK - P-kanal >=100V | 1 | 0.600 | 0.60 | TAHMIN | ACIK |  | Gate-source zener (D11) + seri direnc ZORUNLU (48V > Vgs max)
Q11 | Aux high-side cikis | ACIK - P-FET | 1 | 0.400 | 0.40 | TAHMIN | ACIK |  | Mekanik tutucu fren / fan / solenoid. %100 DC (bootstrap yok)
RS1 | Shunt faz A | 4 mOhm 1W 2512 %1 | 1 | 0.900 | 0.90 | BOM tahmini | AYNI | 2 mOhm (+-16.5A) | Kelvin baglanti
RS2 | Shunt faz B | 4 mOhm 1W 2512 %1 | 1 | 0.900 | 0.90 | BOM tahmini | AYNI | 2 mOhm | Kelvin baglanti
RS3 | Bara donus shunt (low-side) | 2-3 mOhm 2512 | 1 | 0.900 | 0.90 | TAHMIN | YENI |  | Tum alt FET source'lari -> RS3 -> GND. G431 OPAMP PGA -> COMP -> TIM1_BKIN. Kisa devre/shoot-through korumasi
C_BULK | Bara bulk | ACIK - 100V low-ESR elektrolitik/hibrit | 2 | 1.000 | 2.00 | TAHMIN | DEGISTI (63V -> 100V) |  | Ripple akimi hesabi yapilacak. Toplam kapasite azaltilmayacak
C_HB | Yarim kopru lokal MLCC | 2.2uF 100V X7R 1210 | 8 | 0.250 | 2.00 | TAHMIN | YENI (BOM'da aciktan yoktu) |  | Her bacakta 2 adet, ust FET drain - alt FET source arasi, minimum dongu
C_BST | Bootstrap | 1uF 25V X7R 0603 | 4 | 0.030 | 0.12 | TAHMIN | YENI | 0.47uF | BSTx-SHx, driver pinine yakin
C_GVDD | Driver besleme | 10uF 25V X7R 0805 | 2 | 0.080 | 0.16 | TAHMIN | YENI |  | Her DRV8300 GVDD-GND, >=10uF datasheet sarti
D1 | Bara TVS | SMCJ54A | 1 | 0.400 | 0.40 | TAHMIN | DEGISTI (SMBJ58A) |  | Kistirma 80-90V'a dayanir; asil OV korumasi firmware + kapasite
D2-D9 | Gate turn-off diyot | BAT54 / 1N4148W | 8 | 0.050 | 0.40 | BOM tahmini | AYNI |  | 10 Ohm ile seri
D10 | Aux cikis flyback | SS110 / S1B | 1 | 0.150 | 0.15 | BOM tahmini | AYNI |  | Fren bobini icin
D11 | Q10 gate zener | 12-15V zener SOD-323 | 1 | 0.030 | 0.03 | TAHMIN | YENI
D12 | CAN ESD | PESD2CANFD | 1 | 0.300 | 0.30 | TAHMIN | YENI
R_GON | Gate turn-on | 33 Ohm 0603 | 8 | 0.010 | 0.08 | BOM tahmini | AYNI |  | Bring-up'ta ayarlanacak
R_GOFF | Gate turn-off | 10 Ohm 0603 | 8 | 0.010 | 0.08 | BOM tahmini | AYNI |  | Turn-off < 150 ns olmali (DRV8300 min dead-time)
R_CANT | CAN split terminasyon | 60.4 Ohm 0805 x2 + 4.7nF + jumper | 1 | 0.200 | 0.20 | TAHMIN | YENI |  | Zincirin son kartinda takilir
Y1 | Kristal 24MHz | ECS-240-12-37B-CKY-TR | 1 | 0.800 | 0.80 | BOM tahmini | AYNI |  | C=15pF
FB1 | Ferrit | 120R 0603 | 1 | 0.100 | 0.10 | BOM tahmini | AYNI |  | 3.3VA / encoder besleme
RT1 | NTC | 10k NTC 0805 | 1 | 0.250 | 0.25 | BOM tahmini | AYNI |  | FET bakirina yakin
SW1 | Reset butonu | SMD tact switch | 1 | 0.200 | 0.20 | TAHMIN | DEGISTI (BOOT SPDT kaldirildi) |  | NRST. BOOT0 option byte ile (nSWBOOT0=0)
SW2 | CAN adres | 4'lu DIP veya direnc merdiveni | 1 | 0.600 | 0.60 | BOM tahmini | AYNI
LED1-2 | Durum/hata LED | 0603 yesil+kirmizi | 2 | 0.060 | 0.12 | BOM tahmini | AYNI
J1 | Guc+CAN giris | ACIK 4 pin | 1 | 1.200 | 1.20 | BOM tahmini | ACIK |  | 48V GND CANH CANL. Akim: zincirdeki toplam kart akimi
J2 | Guc+CAN cikis | ACIK 4 pin | 1 | 1.200 | 1.20 | BOM tahmini | ACIK |  | Papatya dizimi
J3 | Motor | ACIK 4 pin | 1 | 1.000 | 1.00 | BOM tahmini | ACIK |  | A+ A- B+ B- (BLDC: U V W)
J4 | Harici SPI encoder | 6 pin | 1 | 0.600 | 0.60 | BOM tahmini | AYNI |  | 3V3 GND SPI2
J6 | ENABLE + GPIO | 5 pin | 1 | 0.600 | 0.60 | BOM tahmini | AYNI |  | ENABLE -> U11 + TIM1_BKIN2
J7 | SWD | Tag-Connect veya 2x5 1.27mm | 1 | 0.500 | 0.50 | BOM tahmini | AYNI
J8 | ABI encoder / Hall | 5 pin | 1 | 0.500 | 0.50 | TAHMIN | YENI |  | 5V GND CH1 CH2 CH3 (A/B/Z veya U/V/W). Seri R + klemp, secilebilir pull-up
PASIF | Genel R/C (decoupling, bolucu, pull-down, RC) | 0402/0603 | 90 | 0.020 | 1.80 | BOM tahmini | AYNI |  | PWM ve enable hatlarina pull-down dahil
 |  |  |  | KOMPONENT TOPLAM | 48.54
 |  |  |  | PCB 4 katman (5 adet siparis) | ~7.00
 |  |  |  | KART BASINA | 55.54
KALDIRILANLAR
Ref | Parca | Neden
U3-U6 (eski) | MIC4605-1YM x4 | Yanlis varyant (-1 = HI/LI). 2x DRV8300 ile degistirildi
U11 (eski) | UCC27517DBVR | Fren chopper kaldirildi
Q9 | CSD19534Q5A (chopper) | Fren chopper kaldirildi
J5 | Fren direnci konnektoru | Fren chopper kaldirildi
SW1 (eski) | SW_SPDT BOOT | PB8/CAN RX ile cakisir; nSWBOOT0 kullaniliyor
D1 (eski) | SMBJ58A | SMCJ54A ile degisti

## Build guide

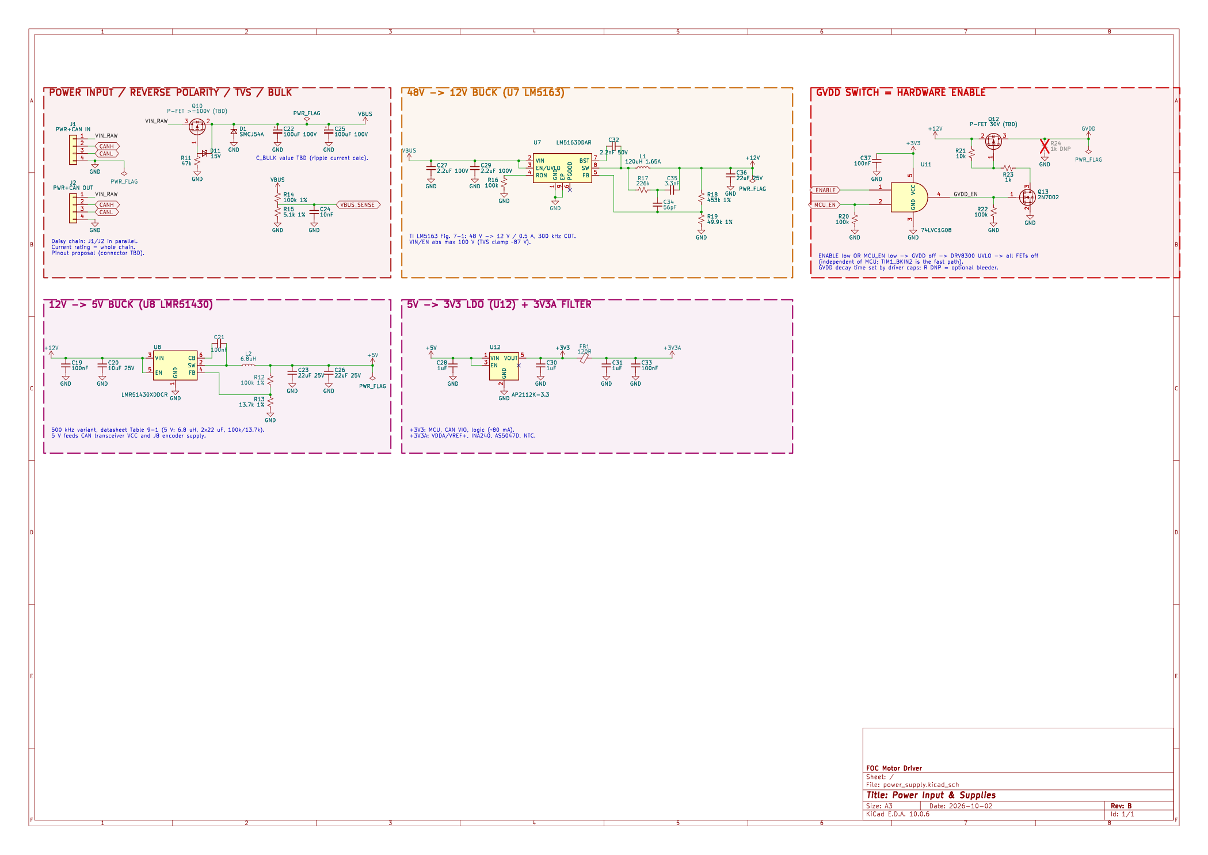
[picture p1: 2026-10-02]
hardware/build/power_supply.png

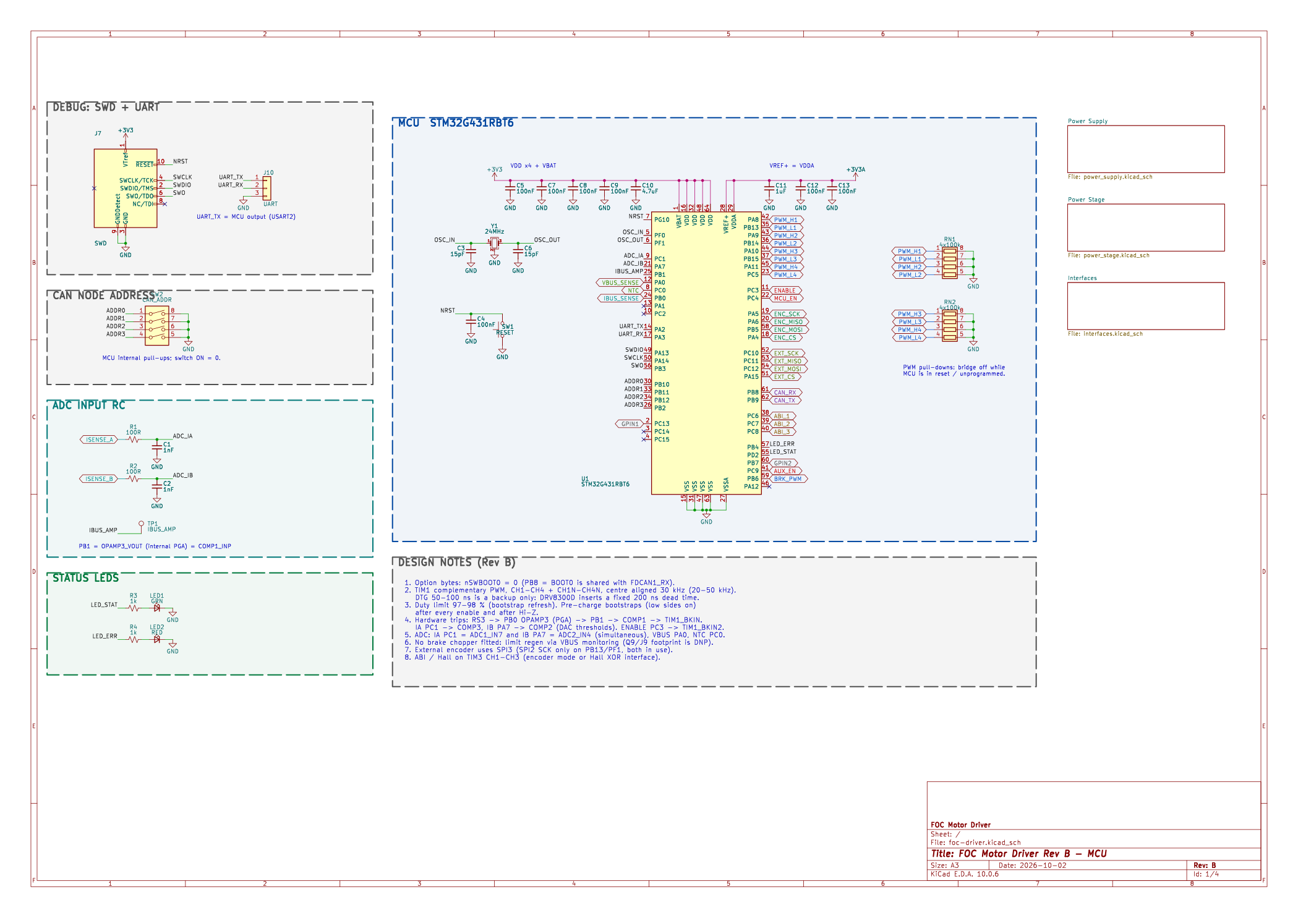
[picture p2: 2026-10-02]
hardware/build/foc-driver.png

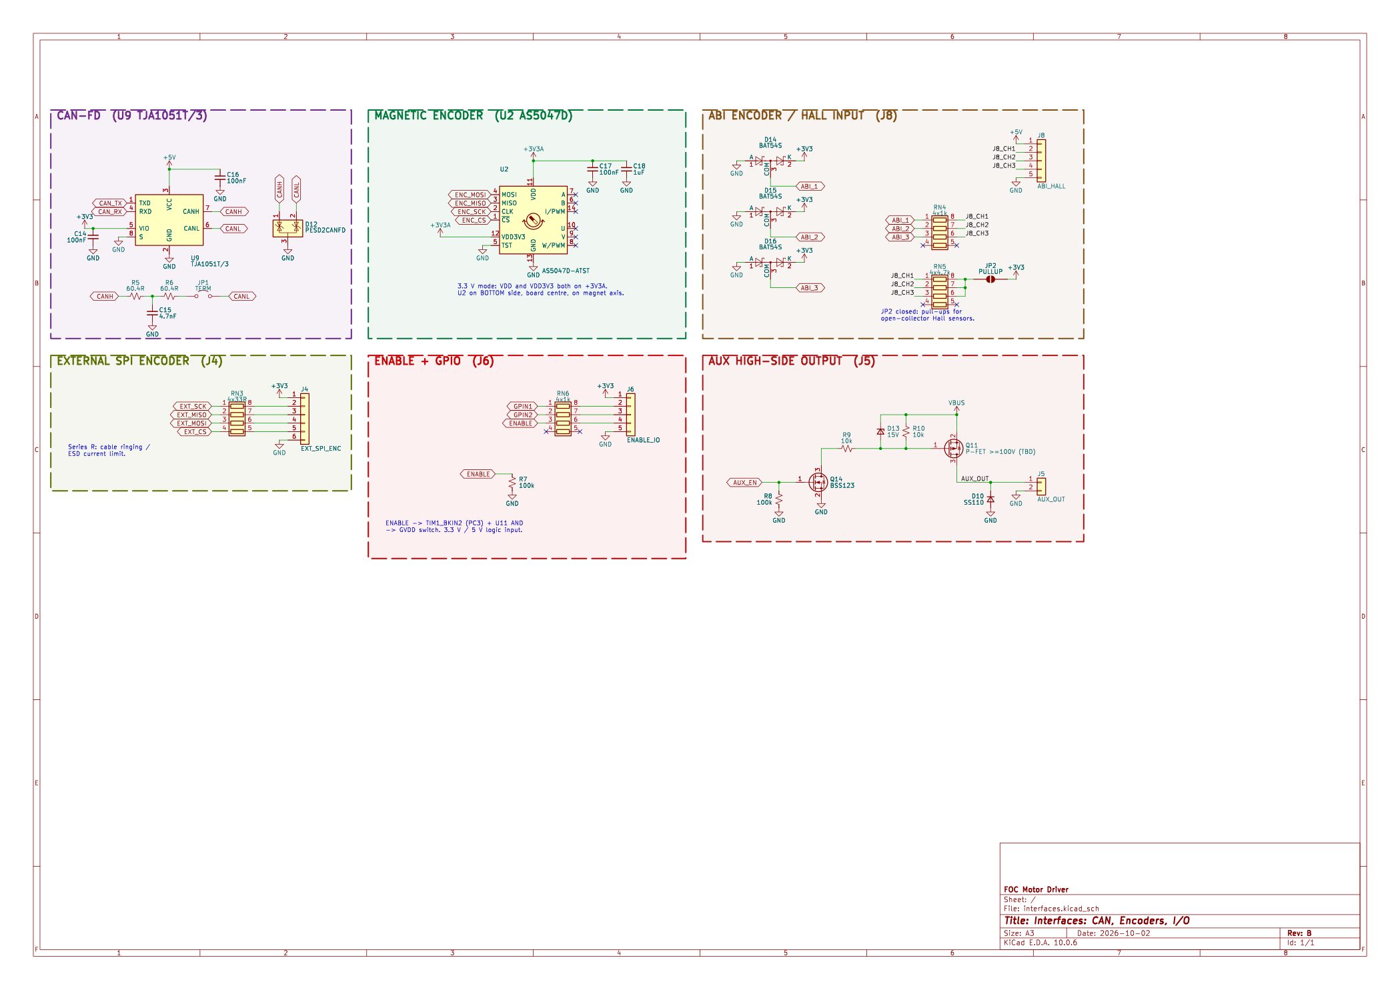
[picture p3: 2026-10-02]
hardware/build/interfaces.png

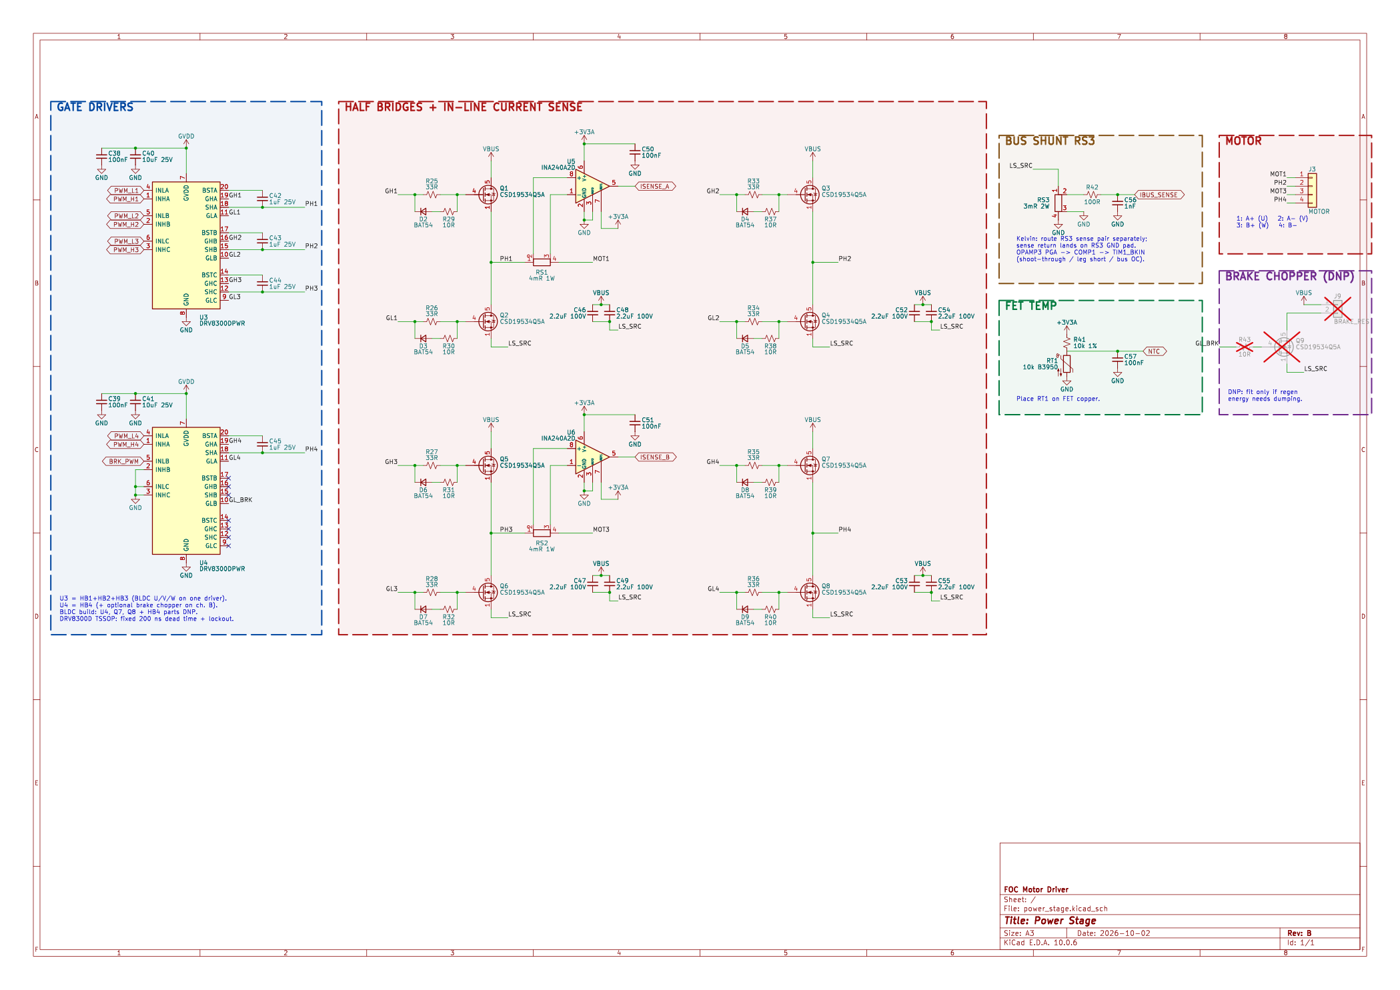
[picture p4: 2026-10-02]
hardware/build/power_stage.png

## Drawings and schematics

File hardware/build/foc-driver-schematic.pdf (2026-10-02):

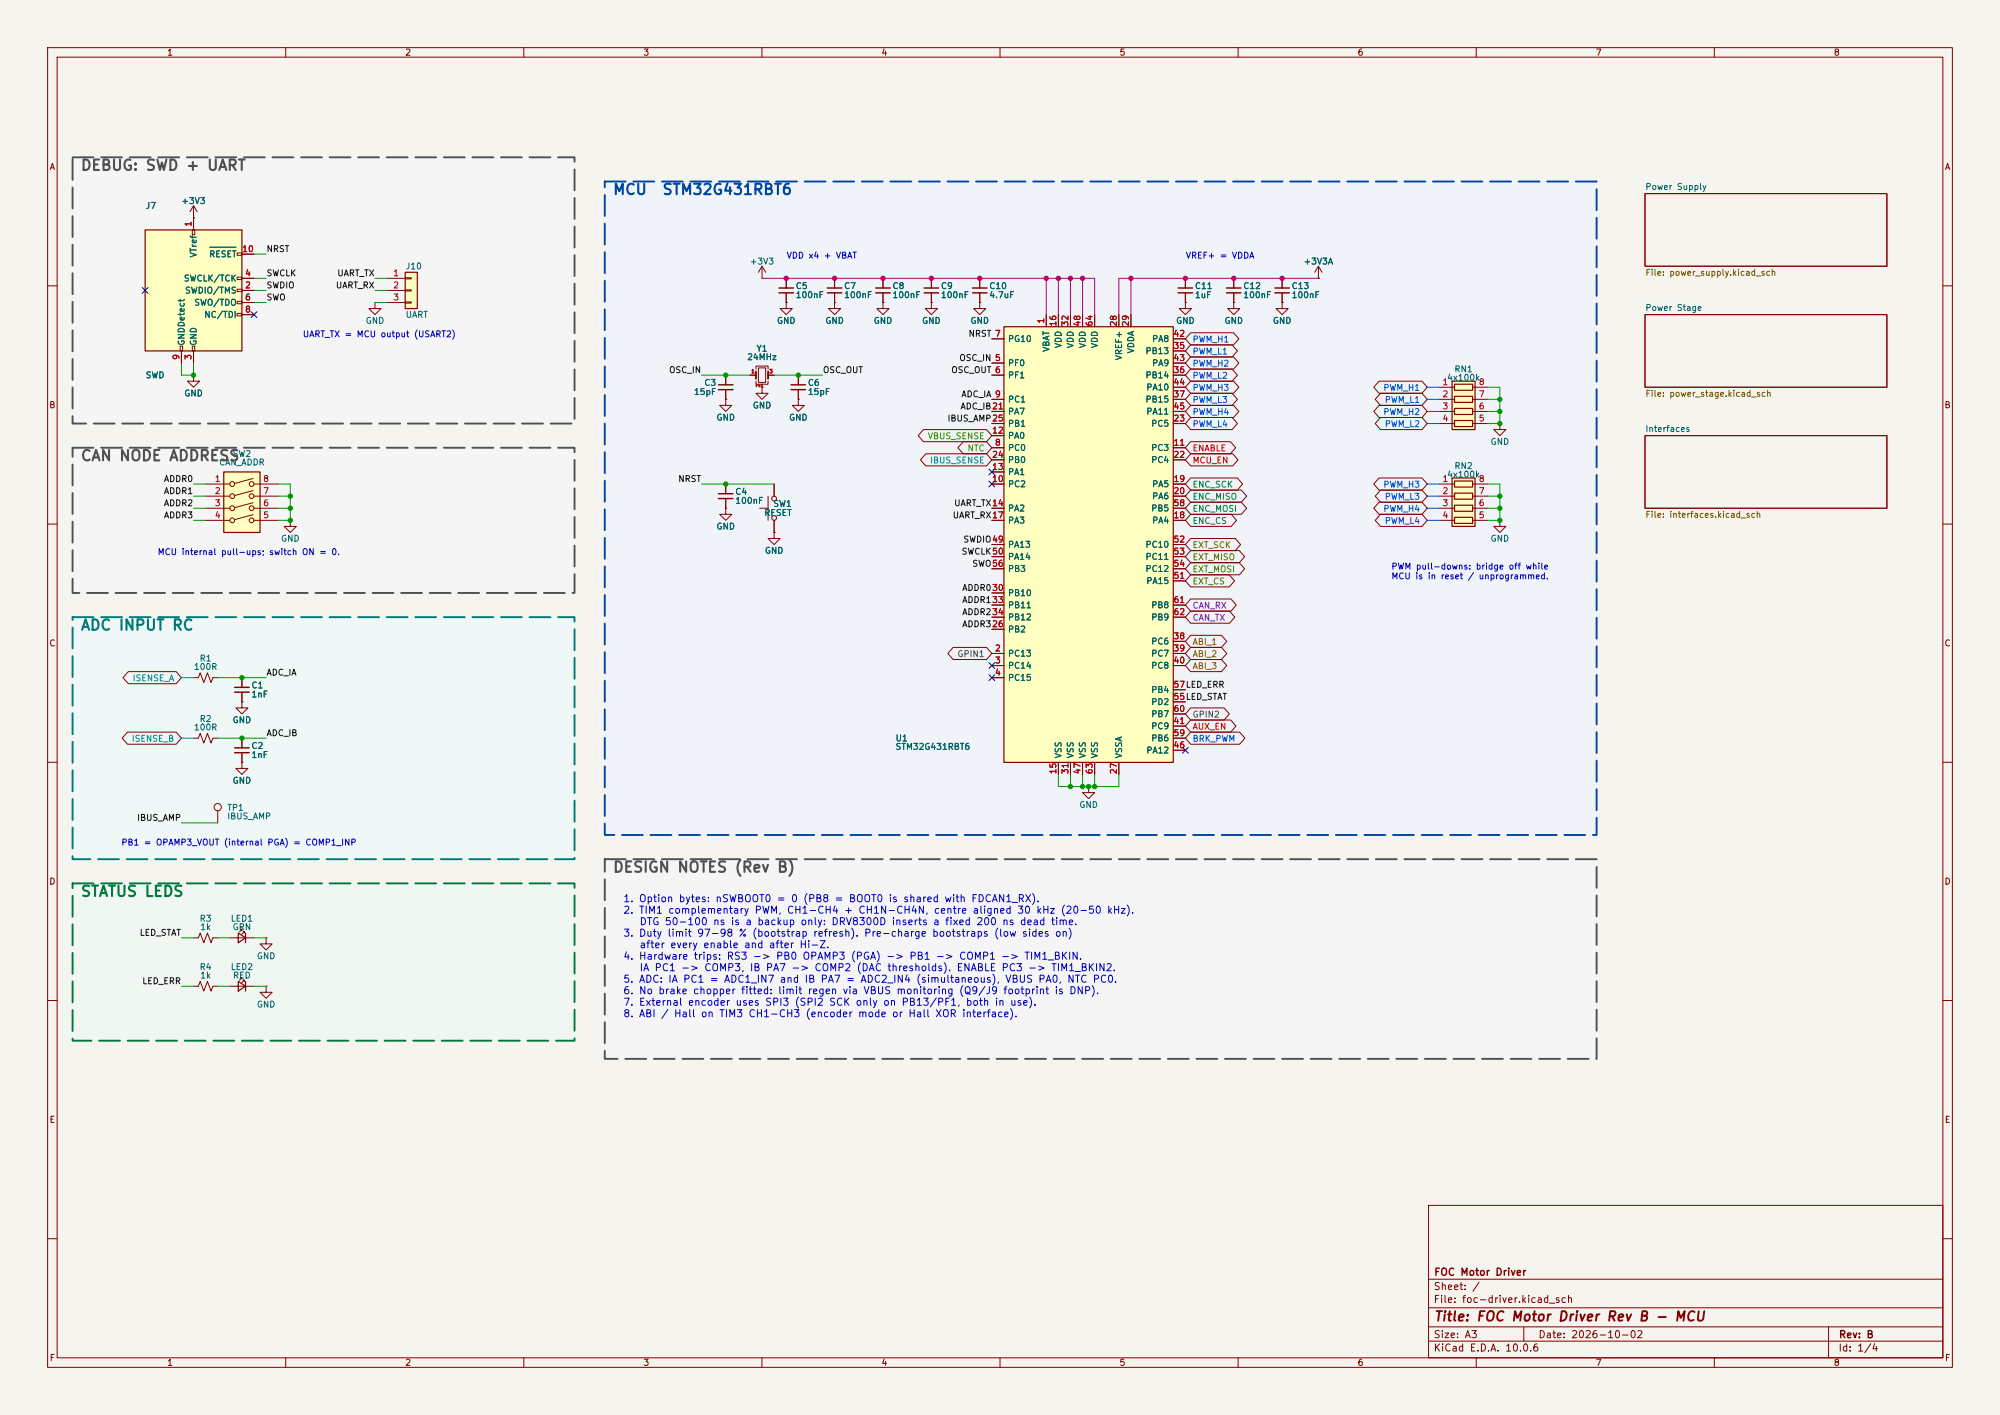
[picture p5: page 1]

ADC_IB MCU internal pull-ups; switch ON = 0. DEBUG: SWD + UART

Power Supply File: power_supply.kicad_sch Power Stage

2. TIM1 complementary PWM, CH1-CH4 + CH1N-CH4N, centre aligned 30 kHz (20-50 kHz).
DTG 50-100 ns is a backup only: DRV8300D inserts a fixed 200 ns dead time.
3. Duty limit 97-98 % (bootstrap refresh). Pre-charge bootstraps (low sides on)
after every enable and after Hi-Z.
4. Hardware trips: RS3 -> PB0 OPAMP3 (PGA) -> PB1 -> COMP1 -> TIM1_BKIN.
IA PC1 -> COMP3, IB PA7 -> COMP2 (DAC thresholds). ENABLE PC3 -> TIM1_BKIN2.
5. ADC: IA PC1 = ADC1_IN7 and IB PA7 = ADC2_IN4 (simultaneous), VBUS PA0, NTC PC0.
6. No brake chopper fitted: limit regen via VBUS monitoring (Q9/J9 footprint is DNP).
7. External encoder uses SPI3 (SPI2 SCK only on PB13/PF1, both in use).
8. ABI / Hall on TIM3 CH1-CH3 (encoder mode or Hall XOR interface).

FOC Motor Driver
Sheet: /
File: foc-driver.kicad_sch
Title: FOC Motor Driver Rev B - MCU

Size: A3 | Rev: B | F Date: 2026-10-02
KiCad E.D.A. 10.0.6 | Id: 1/4

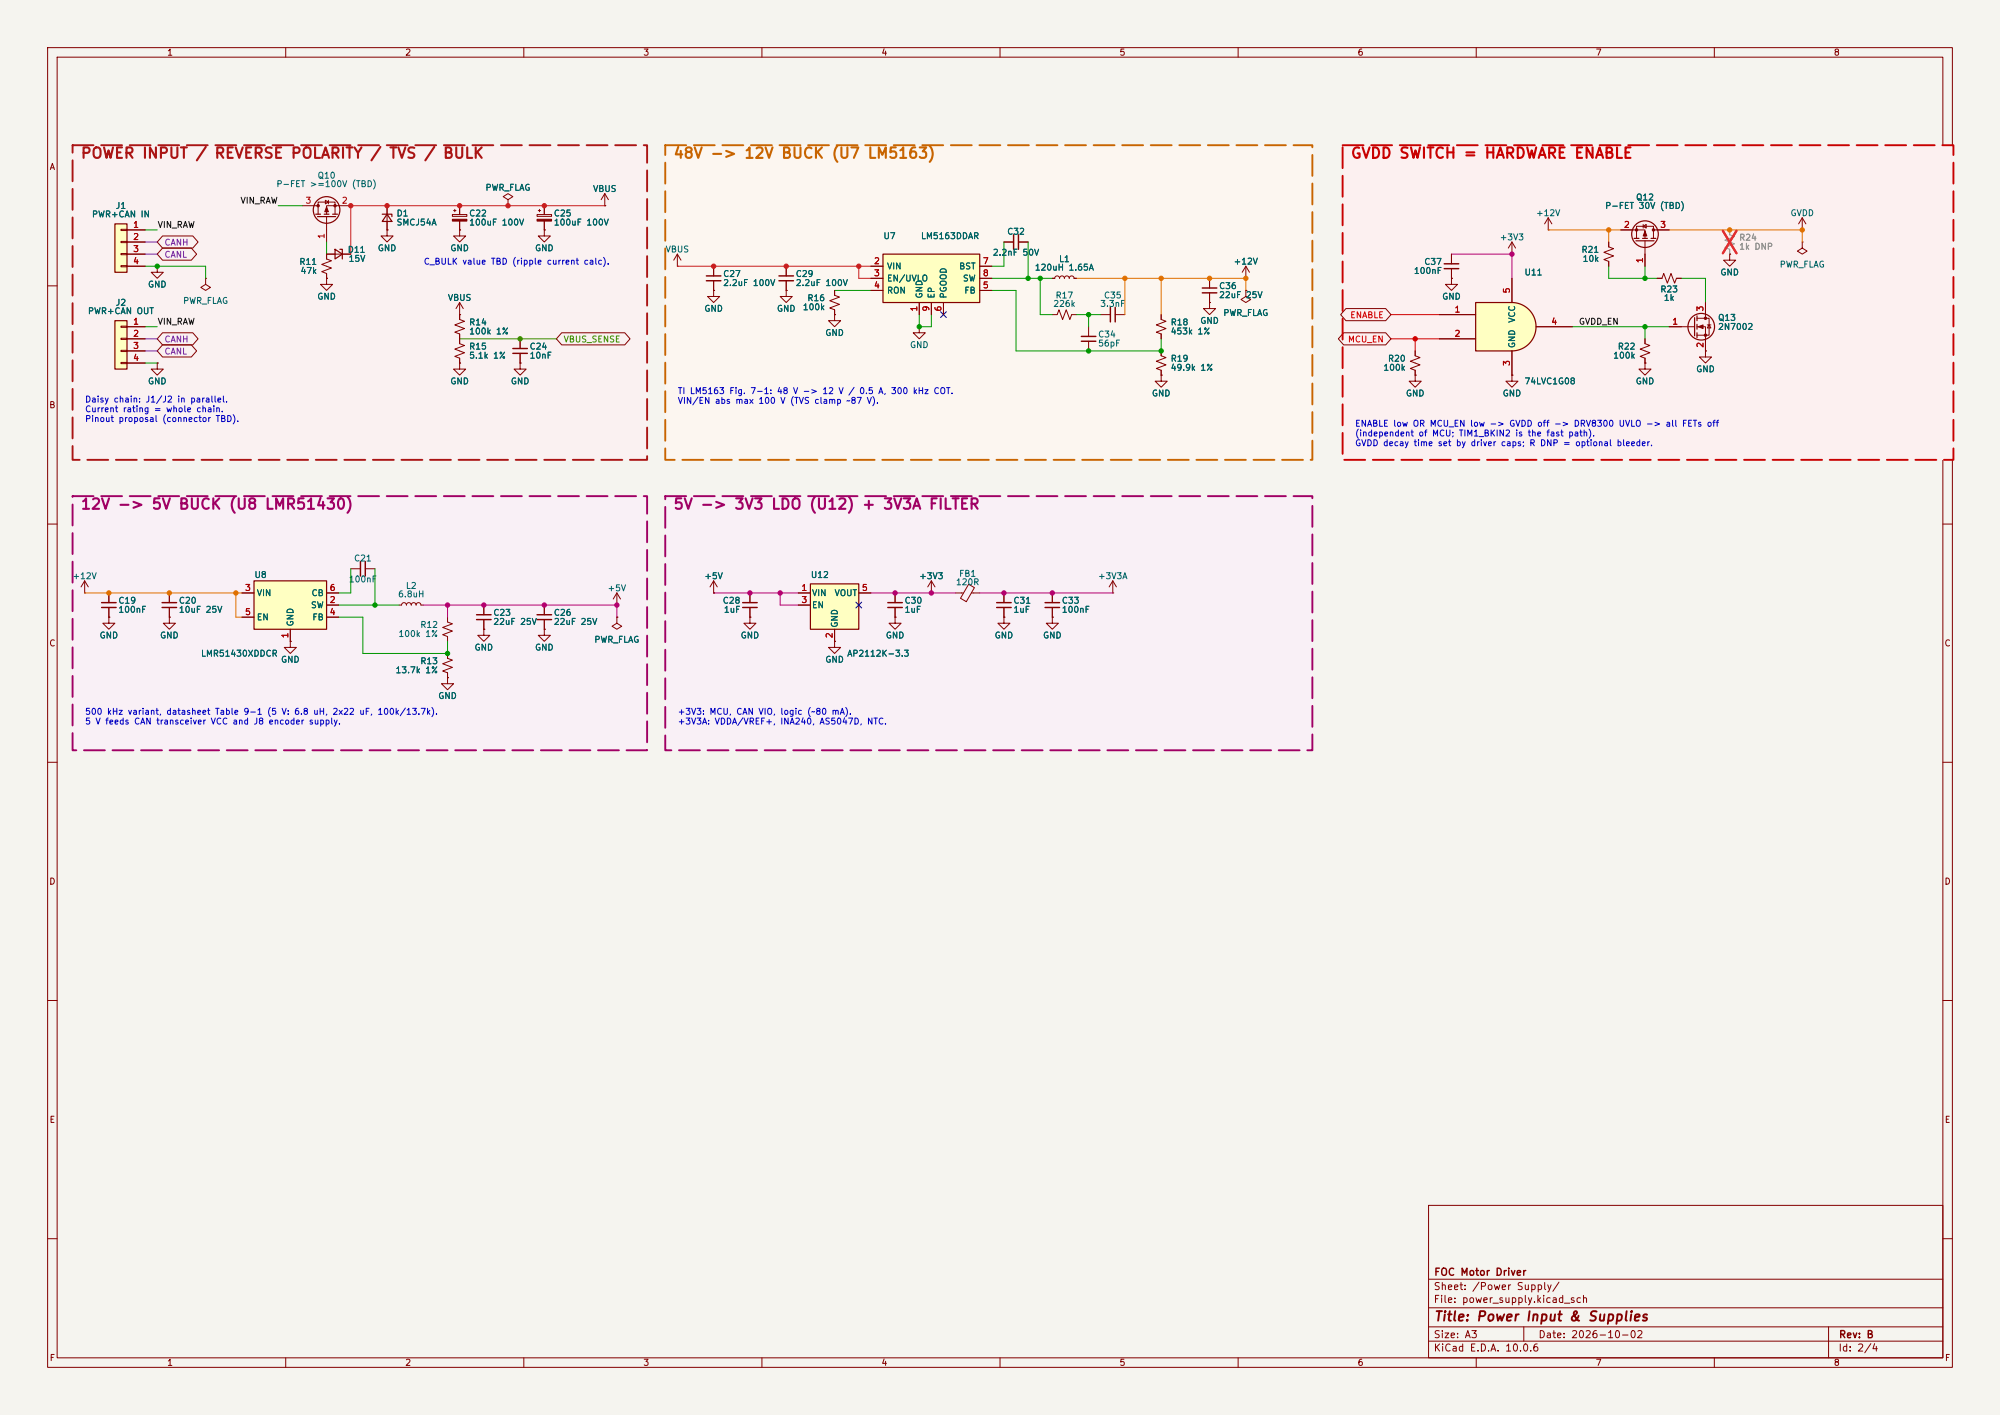
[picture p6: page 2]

Daisy chain: J1/J2 in parallel. Current rating = whole chain. Pinout proposal (connector TBD).

FOC Motor Driver
Sheet: /Power Supply/
File: power_supply.kicad_sch
Title: Power Input & Supplies

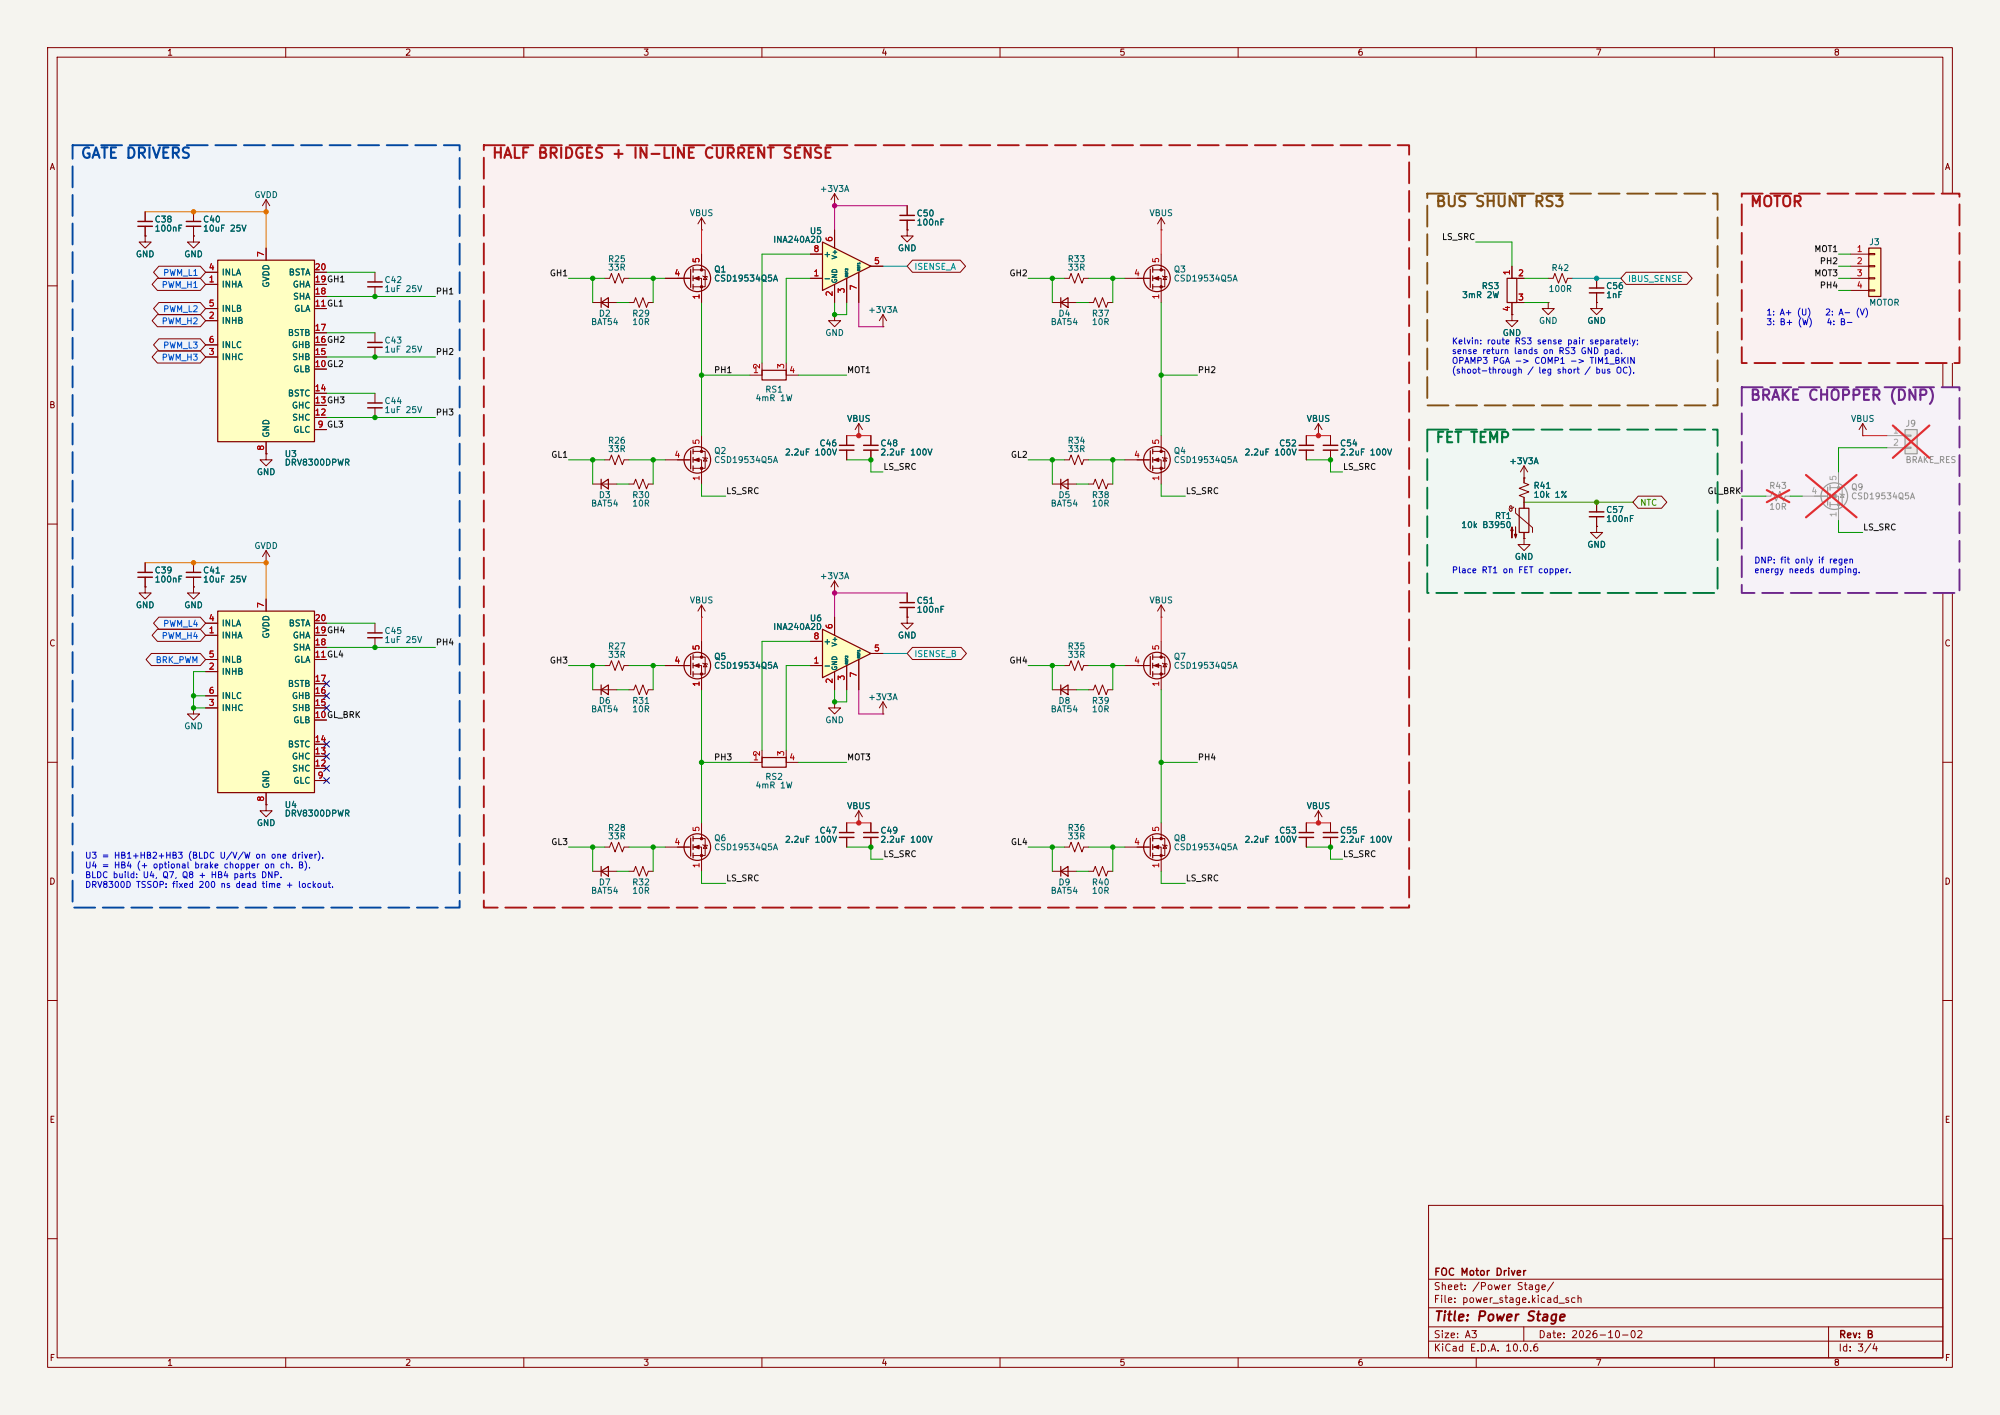
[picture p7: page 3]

energy needs dumping. Kelvin: route RS3 sense pair separately; sense return lands on RS3 GND pad. OPAMP3 PGA -> COMP1 -> TIM1_BKIN

(shoot-through / leg short / bus OC).

Place RT1 on FET copper. FET TEMP

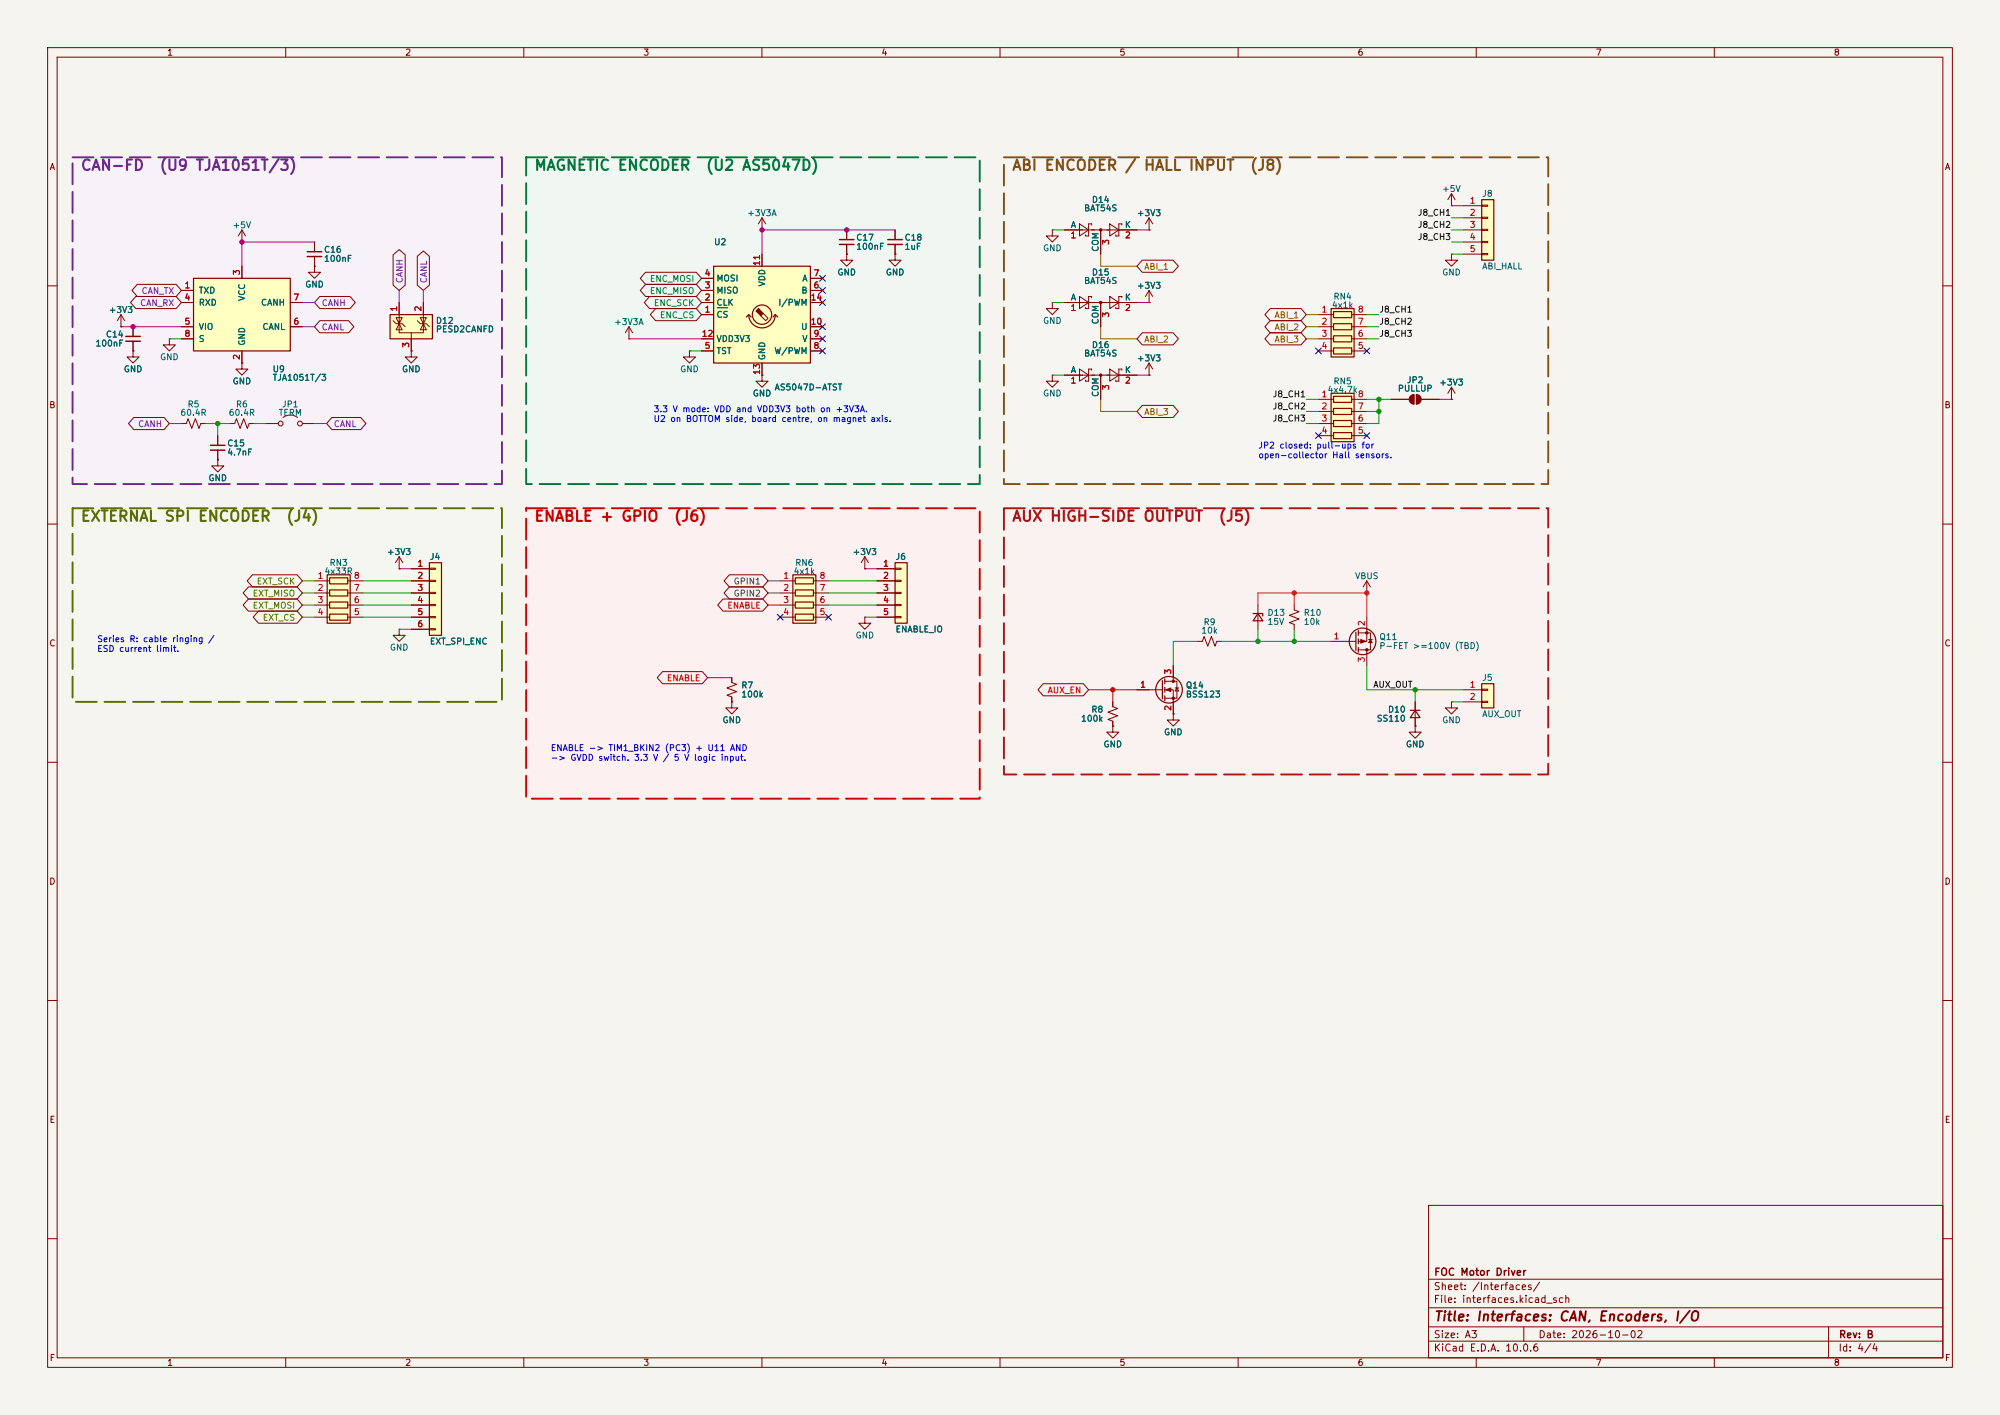
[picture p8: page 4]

3.3 V mode: VDD and VDD3V3 both on +3V3A. U2 on BOTTOM side, board centre, on magnet axis. Series R: cable ringing /

JP2 closed: pull-ups for open-collector Hall sensors. ENABLE -> TIM1_BKIN2 (PC3) + U11 AND -> GVDD switch. 3.3 V / 5 V logic input.

FOC Motor Driver
Sheet: /Interfaces/
File: interfaces.kicad_sch
Title: Interfaces: CAN, Encoders, I/O

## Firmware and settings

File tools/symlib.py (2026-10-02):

"""Builds the project symbol library hardware/foc-driver.kicad_sym."""
import copy
from sexp import Sym as S, find, findall, dumps
import kisch
from kisch import LIB

P = 2.54


def _prop(k, v, x, y, hide=False, just=None):
    e = [S("property"), k, v, [S("at"), x, y, 0], kisch.effects(1.27, just, hide)]
    return e


def _pin(num, name, typ, x, y, ang, length=P, alts=None):
    p = [S("pin"), S(typ), S("line"), [S("at"), x, y, ang], [S("length"), length],
         [S("name"), name, kisch.effects(1.27)], [S("number"), num, kisch.effects(1.27)]]
    for a in alts or []:
        p.append(a)
    return p


def make_ic(name, left, right, top=(), bottom=(), width=15.24, ref="U", value=None,
            footprint="", datasheet="", desc="", kw=""):
    """left/right/top/bottom: lists of (num, name, type[, alts]) or None for a gap.
    Pin pitch 2.54 mm.  Returns flattened symbol sexp."""
    n_side = max(len(left), len(right))
    n_tb = max(len(top), len(bottom), 0)
    width = max(width, (n_tb + 1) * P)
    h = (n_side + 1) * P
    h = round(h / P) * P
    w2 = round(width / 2 / P) * P
    y0 = (n_side - 1) * P / 2   # first pin y
    y0 = round(y0 / 1.27) * 1.27
    body = [S("symbol"), name + "_0_1",
            [S("rectangle"), [S("start"), -w2, y0 + P], [S("end"), w2, y0 - n_side * P],
             [S("stroke"), [S("width"), 0.254], [S("type"), S("default")]],
             [S("fill"), [S("type"), S("background")]]]]
    pins = [S("symbol"), name + "_1_1"]
    top_y, bot_y = y0 + P, y0 - n_side * P

    def add(lst, xy_fn, ang):
        for i, it in enumerate(lst):
            if it is None:
                continue
            num, nm, typ = it[0], it[1], it[2]
            alts = it[3] if len(it) > 3 else None
            x, y = xy_fn(i)
            pins.append(_pin(num, nm, typ, x, y, ang, alts=alts))
    add(left, lambda i: (-w2 - P, y0 - i * P), 0)
    add(right, lambda i: (w2 + P, y0 - i * P), 180)
    tx0 = -(len(top) - 1) * P / 2
    tx0 = round(tx0 / 1.27) * 1.27
    add(top, lambda i: (tx0 + i * P, top_y + P), 270)
    bx0 = round(-(len(bottom) - 1) * P / 2 / 1.27) * 1.27
    add(bottom, lambda i: (bx0 + i * P, bot_y - P), 90)
    sym = [S("symbol"), name,
           [S("pin_names"), [S("offset"), 0.762]],
           [S("exclude_from_sim"), S("no")], [S("in_bom"), S("yes")], [S("on_board"), S("yes")],
           _prop("Reference", ref, -w2, top_y + 1.27 + (P if top else 0), just="left bottom"),
           _prop("Value", value or name, w2, top_y + 1.27 + (P if top else 0), just="right bottom"),
           _prop("Footprint", footprint, 0, 0, True),
           _prop("Datasheet", datasheet, 0, 0, True),
           _prop("Description", desc, 0, 0, True),
           _prop("ki_keywords", kw, 0, 0, True),
           body, pins]
    return sym


def make_power(net):
    s = copy.deepcopy(LIB.get("power:VDD"))
    s[1] = net
    for x in s:
        if isinstance(x, list) and x[0] == "property":
            if x[1] == "Value":
                x[2] = net
            if x[1] == "Description":
                x[2] = 'Power symbol creates a global label with name "%s"' % net
        if isinstance(x, list) and x[0] == "symbol":
            x[1] = net + x[1][3:]
    return s


def mcu_symbol():
    """STM32G431RBTx redrawn, grouped by function.  Pin numbers/names/types and
    alternates are copied verbatim from the KiCad library symbol."""
    src = LIB.get("MCU_ST_STM32G4:STM32G431RBTx")
    raw = {}
    for sub in findall(src, "symbol"):
        for p in findall(sub, "pin"):
            num = find(p, "number")[1]
            raw[num] = (find(p, "name")[1], str(p[1]), findall(p, "alternate"))

    def pn(name):
        m = [k for k, v in raw.items() if v[0] == name]
        assert len(m) == 1, name
        k = m[0]
        return (k, raw[k][0], raw[k][1], raw[k][2])

    def pk(num):
        return (num, raw[num][0], raw[num][1], raw[num][2])

    left = [pn("PG10"), None, pn("PF0"), pn("PF1"), None,
            pn("PC1"), pn("PA7"), pn("PB1"), pn("PA0"), pn("PC0"), pn("PB0"), pn("PA1"), pn("PC2"), None,
            pn("PA2"), pn("PA3"), None,
            pn("PA13"), pn("PA14"), pn("PB3"), None,
            pn("PB10"), pn("PB11"), pn("PB12"), pn("PB2"), None,
            pn("PC13"), pn("PC14"), pn("PC15")]
    right = [pn("PA8"), pn("PB13"), pn("PA9"), pn("PB14"), pn("PA10"), pn("PB15"), pn("PA11"), pn("PC5"), None,
             pn("PC3"), pn("PC4"), None,
             pn("PA5"), pn("PA6"), pn("PB5"), pn("PA4"), None,
             pn("PC10"), pn("PC11"), pn("PC12"), pn("PA15"), None,
             pn("PB8"), pn("PB9"), None,
             pn("PC6"), pn("PC7"), pn("PC8"), None,
             pn("PB4"), pn("PD2"), pn("PB7"), pn("PC9"), pn("PB6"), pn("PA12")]
    top = [pk("1"), pk("16"), pk("32"), pk("48"), pk("64"), None, pk("28"), pk("29")]
    bottom = [pk("15"), pk("31"), pk("47"), pk("63"), None, pk("27")]
    used = [x[0] for x in left + right + top + bottom if x]
    assert sorted(used, key=int) == sorted(raw, key=int), set(raw) - set(used)
    sym = make_ic("STM32G431RBTx", left, right, top, bottom, width=35.56,
                  footprint="Package_QFP:LQFP-64_10x10mm_P0.5mm",
                  datasheet="https://www.st.com/resource/en/datasheet/stm32g431rb.pdf",
                  desc="STM32G431RBT6, Cortex-M4F 170 MHz, 128 KB flash, LQFP-64 (redrawn, grouped by function)",
                  kw="STM32G4 ARM Cortex-M4")
    return sym, raw


def build(path):
    syms = []
    # DRV8300D, TSSOP-20 (PW) pinout, SLVSFG5D Figure 6-2
    syms.append(make_ic(
        "DRV8300DPW",
        left=[("4", "INLA", "input"), ("1", "INHA", "input"), None,
              ("5", "INLB", "input"), ("2", "INHB", "input"), None,
              ("6", "INLC", "input"), ("3", "INHC", "input"), None, None, None, None, None, None],
        right=[("20", "BSTA", "passive"), ("19", "GHA", "output"), ("18", "SHA", "passive"), ("11", "GLA", "output"), None,
               ("17", "BSTB", "passive"), ("16", "GHB", "output"), ("15", "SHB", "passive"), ("10", "GLB", "output"), None,
               ("14", "BSTC", "passive"), ("13", "GHC", "output"), ("12", "SHC", "passive"), ("9", "GLC", "output")],
        top=[("7", "GVDD", "power_in")], bottom=[("8", "GND", "power_in")], width=20.32,
        footprint="Package_SO:TSSOP-20_4.4x6.5mm_P0.65mm",
        datasheet="https://www.ti.com/lit/ds/symlink/drv8300.pdf",
        desc="100-V three-phase half-bridge gate driver, integrated bootstrap diodes, fixed 200 ns dead time, TSSOP-20",
        kw="gate driver half bridge BLDC"))
    # LM5163, SO-8 PowerPAD (DDA)
    syms.append(make_ic(
        "LM5163DDA",
        left=[("2", "VIN", "power_in"), ("3", "EN/UVLO", "input"), ("4", "RON", "passive")],
        right=[("7", "BST", "passive"), ("8", "SW", "power_out"), ("5", "FB", "input")],
        bottom=[("1", "GND", "power_in"), ("9", "EP", "passive"), ("6", "PGOOD", "open_collector")], width=20.32,
        footprint="Package_SO:TI_SO-PowerPAD-8_ThermalVias",
        datasheet="https://www.ti.com/lit/ds/symlink/lm5163.pdf",
        desc="100-V 0.5-A synchronous COT buck converter, SO-8 PowerPAD",
        kw="buck regulator 100V"))
    mcu, raw = mcu_symbol()
    syms.append(mcu)
    for net in ["+3V3", "+3V3A", "+5V", "+12V", "GVDD", "VBUS"]:
        syms.append(make_power(net))
    lib = [S("kicad_symbol_lib"), [S("version"), 20251024], [S("generator"), "kisch"],
           [S("generator_version"), "10.0"]] + syms
    open(path, "w").write(dumps(lib) + "\n")
    return syms, raw


if __name__ == "__main__":
    import sys
    syms, raw = build(sys.argv[1])
    # verify MCU pins identical to library original
    from kisch import sym_pins
    mine = {p["num"]: (p["name"], p["type"]) for p in sym_pins(syms[2])}
    orig = {k: (v[0], v[1]) for k, v in raw.items()}
    assert mine == orig, "MCU pin mismatch"
    print("ok", len(mine), "MCU pins identical")

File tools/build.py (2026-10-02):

#!/usr/bin/env python3
"""Generates the FOC driver KiCad project schematics into ../hardware."""
import json
import os
import sys

sys.path.insert(0, os.path.dirname(os.path.abspath(__file__)))
import symlib
from common import HW, Ref
import kisch
from kisch import Sheet, Project

PROJ = "foc-driver"


def write_project():
    netclasses = [
        ("Default", None, []),
        ("HV_Power", "#C81E1E", ["VBUS", "VIN_RAW", "LS_SRC", "PH*", "MOT*", "SW_*12V", "BRK_RES*"]),
        ("Gate_Power", "#E07000", ["+12V", "GVDD", "GVDD_*", "*12V*"]),
        ("LV_Power", "#B4006E", ["+5V", "+3V3", "+3V3A", "*5V*"]),
        ("Gate", "#A05000", ["GH*", "GL*"]),
        ("PWM", "#0050C8", ["PWM_*", "BRK_PWM"]),
        ("Current_Sense", "#008C8C", ["ISENSE_*", "IBUS_*", "ISA*", "ISB*"]),
        ("Analog", "#3C8C00", ["VBUS_SENSE", "NTC"]),
        ("Safety", "#D00000", ["ENABLE*", "MCU_EN", "GVDD_EN", "AUX*"]),
        ("CAN", "#7828A0", ["CAN*", "FDCAN*"]),
        ("SPI_ENC", "#00823C", ["ENC_*"]),
        ("SPI_EXT", "#5A7800", ["EXT_*"]),
        ("ABI_HALL", "#8C5A00", ["ABI*", "HALL*", "J8_*"]),
        ("ADC", "#008C8C", ["ADC_*"]),
        ("Debug", "#505050", ["SWD*", "SWO", "NRST", "UART_*", "ADDR*", "LED_*", "GPIN*", "OSC_*"]),
    ]
    classes, patterns = [], []
    for name, col, pats in netclasses:
        c = {"name": name, "bus_width": 12, "clearance": 0.2, "track_width": 0.25, "via_diameter": 0.6,
             "via_drill": 0.3, "wire_width": 6, "line_style": 0, "priority": 2147483647 if name == "Default" else 10,
             "pcb_color": "rgba(0, 0, 0, 0.000)", "schematic_color": "rgba(0, 0, 0, 0.000)"}
        if col:
            r, g, b = int(col[1:3], 16), int(col[3:5], 16), int(col[5:7], 16)
            c["schematic_color"] = "rgb(%d, %d, %d)" % (r, g, b)
        classes.append(c)
        for p in pats:
            patterns.append({"netclass": name, "pattern": p})
    pro = {
        "meta": {"filename": PROJ + ".kicad_pro", "version": 3},
        "net_settings": {"classes": classes, "meta": {"version": 4}, "netclass_assignments": None,
                         "netclass_patterns": patterns},
        "schematic": {"drawing": {"default_text_size": 50.0, "label_size_ratio": 0.375,
                                  "pin_symbol_size": 25.0, "text_offset_ratio": 0.15},
                      "meta": {"version": 1}},
        "sheets": [], "text_variables": {}, "libraries": {"pinned_footprint_libs": [], "pinned_symbol_libs": []},
    }
    with open(os.path.join(HW, PROJ + ".kicad_pro"), "w") as f:
        json.dump(pro, f, indent=2)
    with open(os.path.join(HW, "sym-lib-table"), "w") as f:
        f.write('(sym_lib_table\n  (version 7)\n  (lib (name "foc-driver")(type "KiCad")'
                '(uri "${KIPRJMOD}/foc-driver.kicad_sym")(options "")(descr "FOC driver project symbols"))\n)\n')


def main():
    os.makedirs(HW, exist_ok=True)
    symlib.build(os.path.join(HW, "foc-driver.kicad_sym"))
    write_project()
    ref = Ref()
    import sheet_power_stage
    root = Sheet("FOC driver", PROJ + ".kicad_sch", "A3", title="FOC Motor Driver Rev B - MCU")
    itf = Sheet("Interfaces", "interfaces.kicad_sch", "A3", title="Interfaces: CAN, Encoders, I/O")
    itf.tag = "IF"
    ps = Sheet("Power Stage", "power_stage.kicad_sch", "A3", title="Power Stage")
    prj = Project(PROJ, root)
    root.tag, ps.tag = "MCU", "PST"
    import sheet_power_supply
    pw = Sheet("Power Supply", "power_supply.kicad_sch", "A3", title="Power Input & Supplies")
    pw.tag = "PSU"
    prj.add_sub(pw, 345.44, 40.64, 50.8, 15.24)
    prj.add_sub(ps, 345.44, 66.04, 50.8, 15.24)
    prj.add_sub(itf, 345.44, 91.44, 50.8, 15.24)
    import sheet_root
    sheet_root.build(root, ref)
    sheet_root.build_interfaces(itf, ref)
    sheet_power_supply.build(pw, ref)
    sheet_power_stage.build(ps, ref)
    from common import annotate
    annotate([root, itf, pw, ps])
    g = prj.write(HW)
    print("global nets:", len(g))


if __name__ == "__main__":
    main()

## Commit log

2026-10-02 FOC motor driver Rev B: handover docs, BOM, KiCad schematics, generator tools, datasheets
    [BOM_revB.csv, foc-driver.kicad_sch, interfaces.kicad_sch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]
2026-10-02 Move HB3 to U3: U3 drives HB1-HB3, U4 drives HB4
    BLDC (U/V/W = HB1-HB3) now runs on a single DRV8300; U4, Q7, Q8 and the
    HB4 parts are marked with a Variant field for a DNP BLDC build. Optional
    brake chopper moves to U4 channel B. DRV8300 symbol inputs reordered
    (INL before INH) for clean GND ties. Handover K7/4.2, BOM and README updated.
    [BOM_revB.csv, power_stage.kicad_sch]
